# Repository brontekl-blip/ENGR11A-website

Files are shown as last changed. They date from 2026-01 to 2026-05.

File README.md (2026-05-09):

**Automatic Medicine Dispenser**

<p>
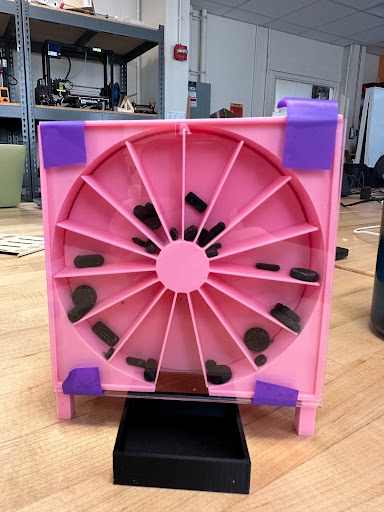
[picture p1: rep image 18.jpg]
  
</p> 
<p>
  Currently, older adults with dementia or general memory issues struggle to remember to take their medications and manage multiple medications. This means that these individuals may not take their medications at the correct times or at all and might need help from a caretaker. We want these individuals to be able to manage their medications independently and have confidence in themselves. Our project is a medicine dispenser that can be preloaded for a full week, including separate morning and night compartments, for a total of 14 functional compartments and 1 refill position. 
</p>

**Bill of Materials**
- 2 9V batteries  
- A small breadboard (you can use basically any breadboard as long as it accommodates the necessary design size) 
- A couple of different jumper wires (recommended package - [link](https://a.co/d/06EYdTq6)) 
- A USB Printer Cable
- An LED (depending on how much light you want, get as many LEDs).
- DC3V-12V DC Geared Motor (recommended package - [link](https://a.co/d/02fzENU2)) 
- 2 regular wires
- A cable to connect the battery 
- Resistor (higher than 222 ohms) 
- A 9V battery clip
- A DRV8833 Dual H-Bridge DC Motor Driver Module H
- 4 Hall Effect Magnetic Sensor Module 3144E  ([link](https://a.co/d/08p1yAlN))
- 32 Magnets, diameter of 5mm and depth of 2-3mm
- PLA Printer Filament Roll

**Required/Recommended Tools**
- Arduino-compatible coding program
- A soldering machine is not needed, but is suggested; it is commonly found in a library.
- A Rubber Mallet
- 3D Printer (originally designed for print on Prusa MINI)

**Mechanical Assembly**
<p>
  PS - The place in which you place your jumper wires to the breadboards, for example, for hall sensors, is based on how you coded into the Arduino. In this case, or if you are using the <a href="https://docs.google.com/document/d/1jkpZ4H0KWvsoafJ_Ff6-uf_Do_P35tXl_jxYF_B4JnI/edit?tab=t.nf3fixb14pqj">original code</a>, the hall sensors go to pin number 2, 3, 4, 5, the buzzer to pin number 6 and then lead to 13. For an easier time, try to color coordinate. For example, as you will see in my design, I try to use black or darker jumper wires for ground, a lighter color such as yellow for power, and then medium colors such as blue and purple for signals.
</p>
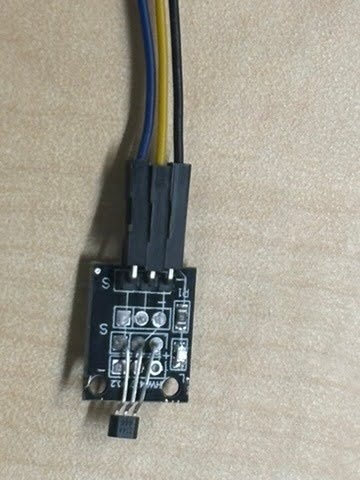
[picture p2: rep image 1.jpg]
1. For every hall sensor, using the male-to-female jumper wires, connect them to the hall sensor and buzzer, remembering which colors of wires go where (look in the picture for reference) 
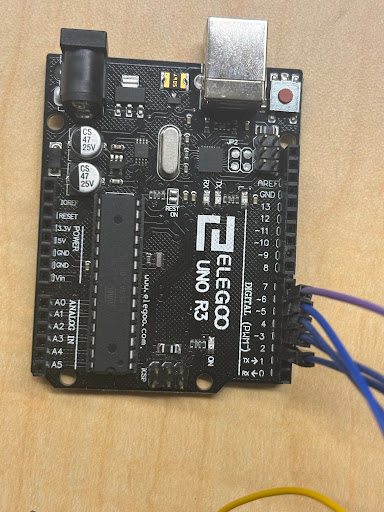
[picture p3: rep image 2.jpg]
2. Now connect the blue jumper wire (or whatever color you used) to the corresponding pin numbers (2, 3, 4, 5) and the purple jumper wire (buzzer) to pin number 6. 
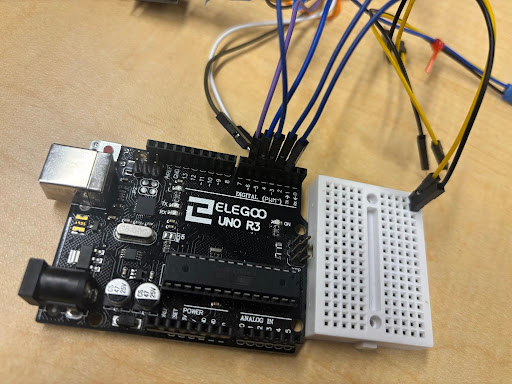
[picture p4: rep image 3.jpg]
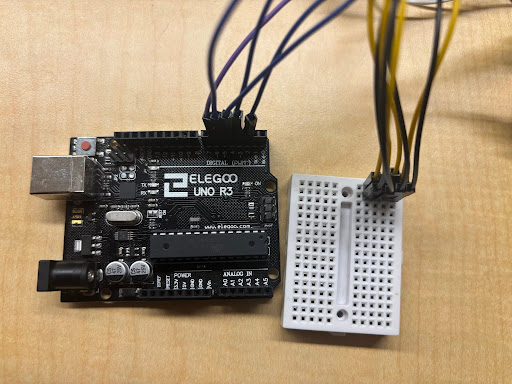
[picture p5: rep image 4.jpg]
3. Then, using the breadboard, align all the yellow jumper wire (power) on a single row then the black jumper wires on the row below it.  
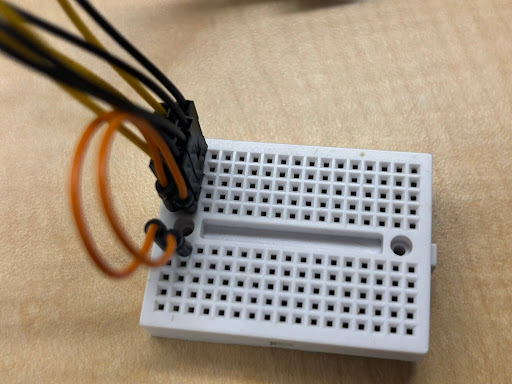
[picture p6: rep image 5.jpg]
4. If using the small breadboard, use two male to male wires to connect each row to the corresponding row next to it. 
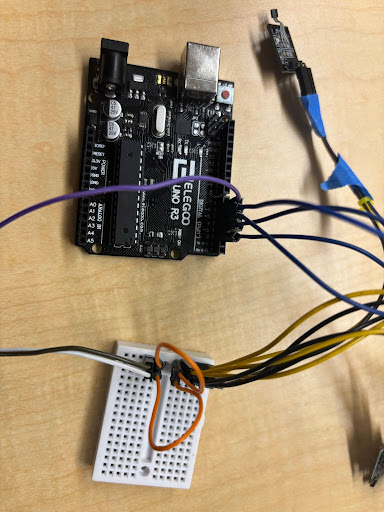
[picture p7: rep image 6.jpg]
5. Then connect the corresponding buzzer cable to power and ground. (In this case, power was connected through a white jumper cable and a brown cable for ground). 
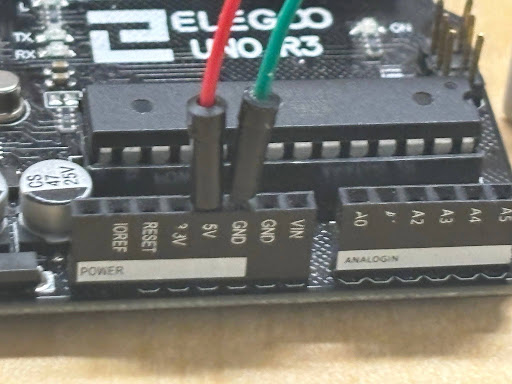
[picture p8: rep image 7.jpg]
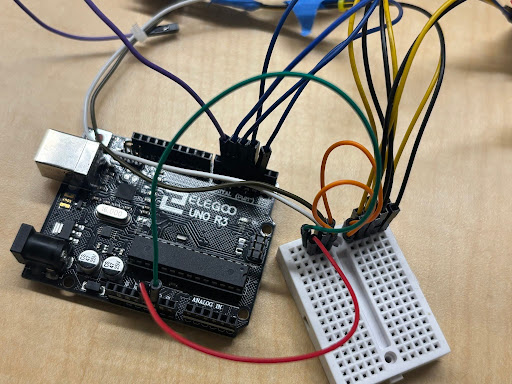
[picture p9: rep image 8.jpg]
6. Using male-to-male wires, connect one of the wires to 5V on the Arduino board and then to the power supply on the breadboard. Then connect one of the wires to GND on the Arduino board and then to the ground corresponding on the breadboard. (red is power and green is ground.)  
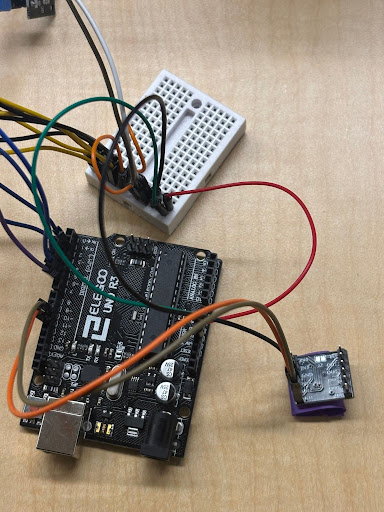
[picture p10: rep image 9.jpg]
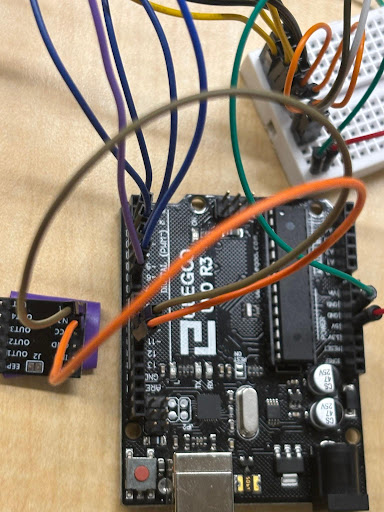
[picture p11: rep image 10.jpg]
7. Then move on to the Dual H-Bridge; connect IN1 and IN2 to the corresponding pin number on the arduino board, pin 10 and pin 11.  
8. Using another male-to-female connector, connect GND from the dual H-bridge to one of the spaces on the row of GND on the breadboard.
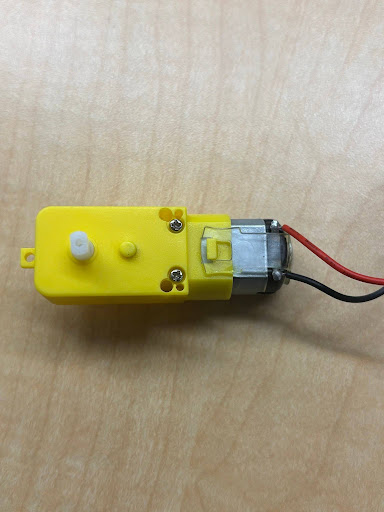
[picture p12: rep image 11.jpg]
9. Then using 2 wires, slowly strip some insulating part and tie and wrap the wires over the little flaps from the tip of the wire. Bonus points if you can solder them together for a stronger connection. 
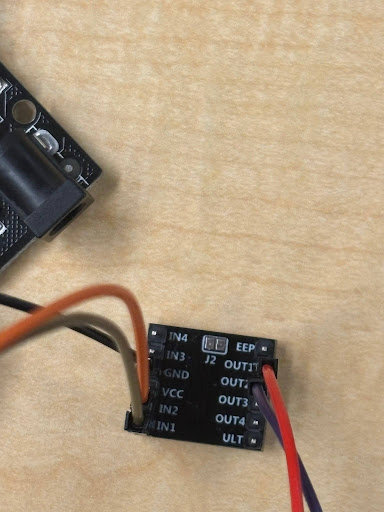
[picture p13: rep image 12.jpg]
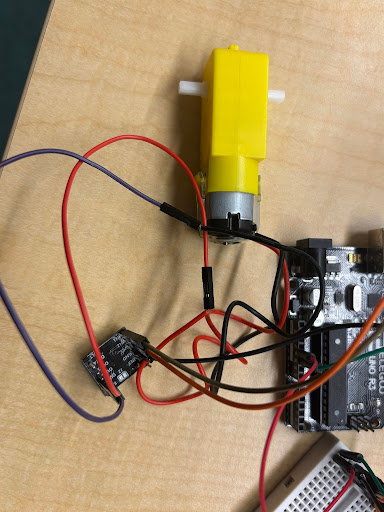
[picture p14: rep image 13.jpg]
10. Then use two female-to-female wires, to connect the wires to OUT1 and OUT2, connecting the whole motor to wires, (this doesn’t matter which one; it only determines which direction the motor spins)  
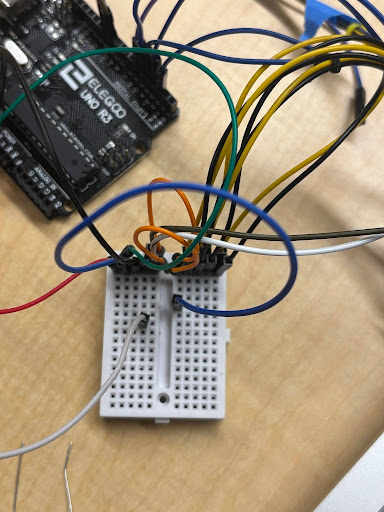
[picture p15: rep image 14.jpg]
11. Use an additional male-to-male wire, to connect to the designated ground breadboard and connect it to an additional row on the breadboard (look at the image for an example; it is the blue wire) 
12. Then connect the black wire of the 9V battery clip to the row connected to GND of the Arduino board.
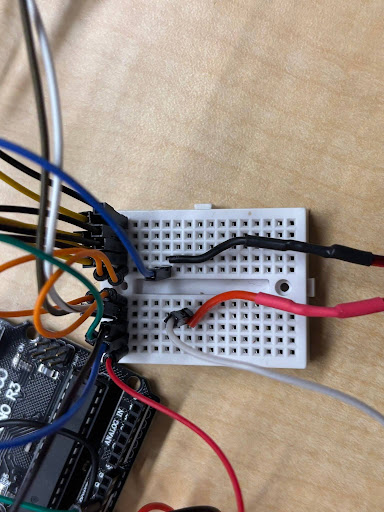
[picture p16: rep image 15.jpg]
13. Using a male-to-female connector, connect the pin labeled EEP on the breadboard, then connect the red wire for the battery to it. (For more context, the white wire connects to EEP on board 2.) 
14. To connect the LED, using a male-to-male connector, connect the LED pin number, in this case 13, to the breadboard on an empty row. (This is so you have multiple LED pins and do not have to program or use additional pin numbers).
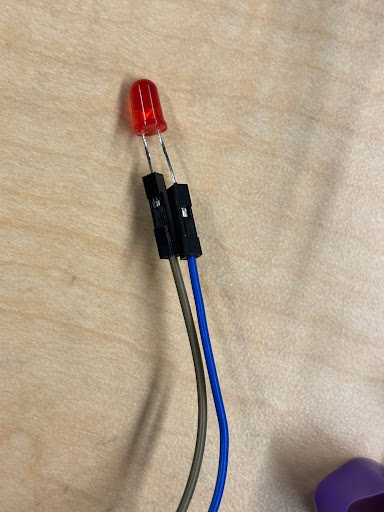
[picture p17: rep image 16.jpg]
15. Connect both LED pins to a male-to-female jumper wire (making sure to remember which one is which); this is to make sure that the LEDs have more flexibility. In this case, the blue wire is the longer leg of the LED, and the black wire is the shorter leg of the LED. 
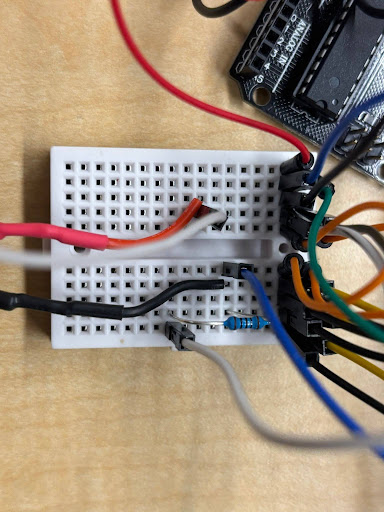
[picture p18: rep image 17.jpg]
16. Then take a resistor and put one of the pins of the resistor to the row that connects to the LED pin number and one to the designated ground rows on the breadboards. 
17. Then connect the LED to both the designated ground row and the LED row. Connect the wire with the shorter leg (cathode) to a GND row and the longer leg (anode) to the row that connects to the LED pin number.
18. To start, get the code file from above, then plug the USB printer cable into the Arduino board and back into your computer (based on the circuit board you are using, you might need a different cable to connect your circuit board to your computer).

**3D Print and Assembly**
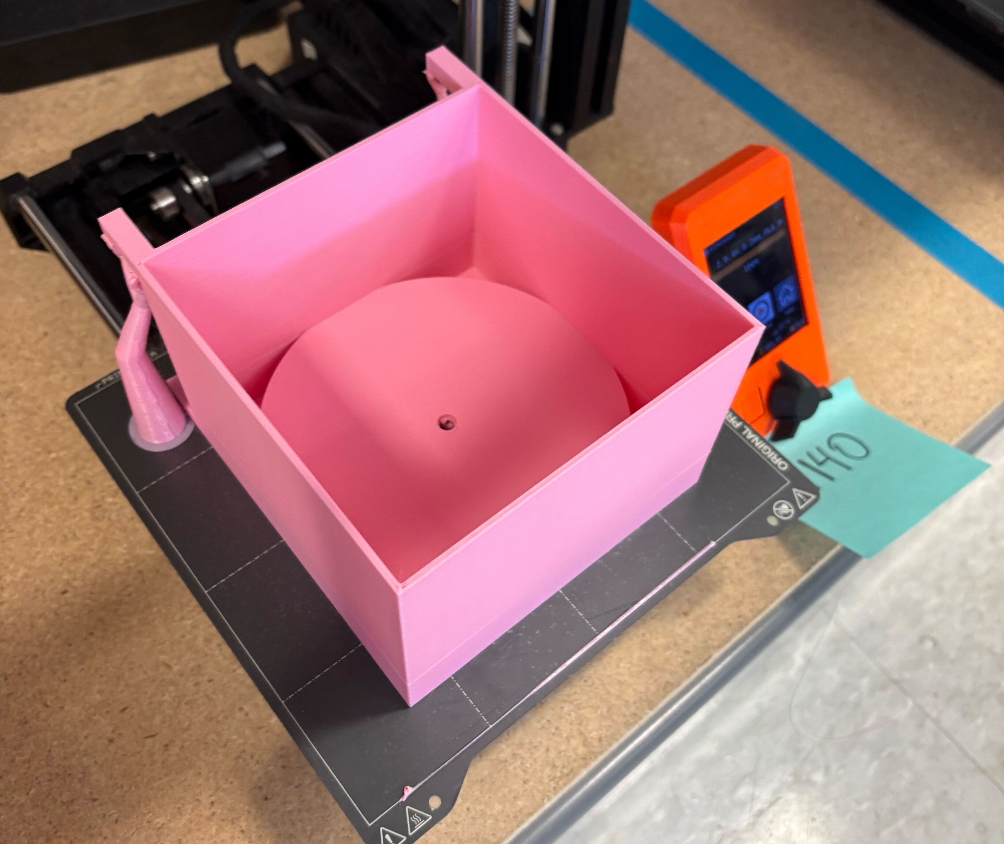
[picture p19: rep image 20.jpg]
1. Print Settings: Final Cycle Outer Box should be printed on its front face, with automatic paint-on supports. 
2. Print the <a href="./Final Cycle Outer Box.stl" download>Final Cycle Outer Box</a>
3. Print the <a href="./Final Cycle Wheel.stl" download>Final Cycle Outer Box</a>
4. Print the <a href="./Final Cycle Medicine Tray.stl" download>Final Cycle Outer Box</a>
5. Put magnets in the designated holes, using a mallet to fully insert. Ensure that each magnet is facing the correct way before fully inserting, preferably using the hall effect sensor to confirm it is activated. If a magnet is placed backwards, carefully use a heatgun to soften the surrounding plastic, then use a stronger magnet to pull it out of the hole. After this, you will most likely need to super glue the magnet back into place, since the hole will no longer be a snug fit. If the magnets are too small, you can super glue them into place. 
6. Trim down the motor shaft so the wheel does not excessively protrude out the front of the outer box.
7. Insert the motor shaft through the back of the outer box and into the back of the wheel. You may choose to glue the shaft into its socket on the back of the wheel, but only do this if you are certain the wheel is not excessively protruding out the front.
8. Secure the motor in place on the back of the outer box, ensuring the shaft is perpendicular to the back of the outer box. You may use tape, glue, or modify the outer box print to include a mount.

**Suggested Path to Functionality**
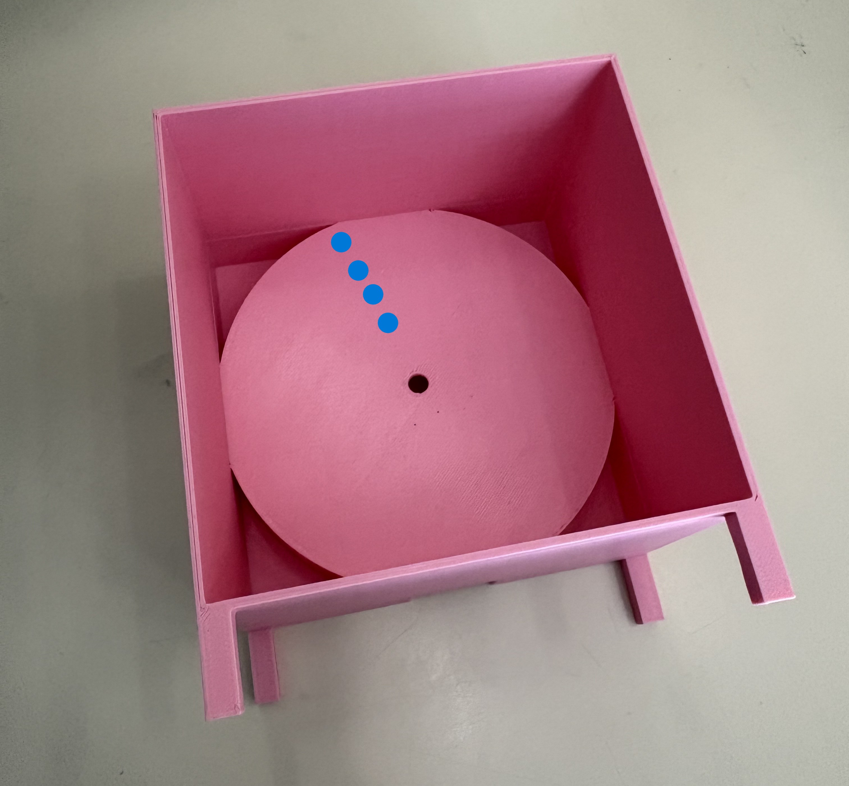
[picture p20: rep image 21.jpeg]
1. Attach the hall effect sensors to the back of the outer box in the positions where each magnet slot would align. Ensure the correct hall effect sensor placement based on the code and pins. Below is the approximate suggested location for positioning. 
2. Add a door, latch, and hinge to the front of the box so that it can be opened for refill and closed to prevent medicine from falling out when upright and functional.
3. Add a door, latch, and hinge to the back of the box so that it can be opened for maintenance and closed during usage.
4. Modify code to release medication at the desired times of day.

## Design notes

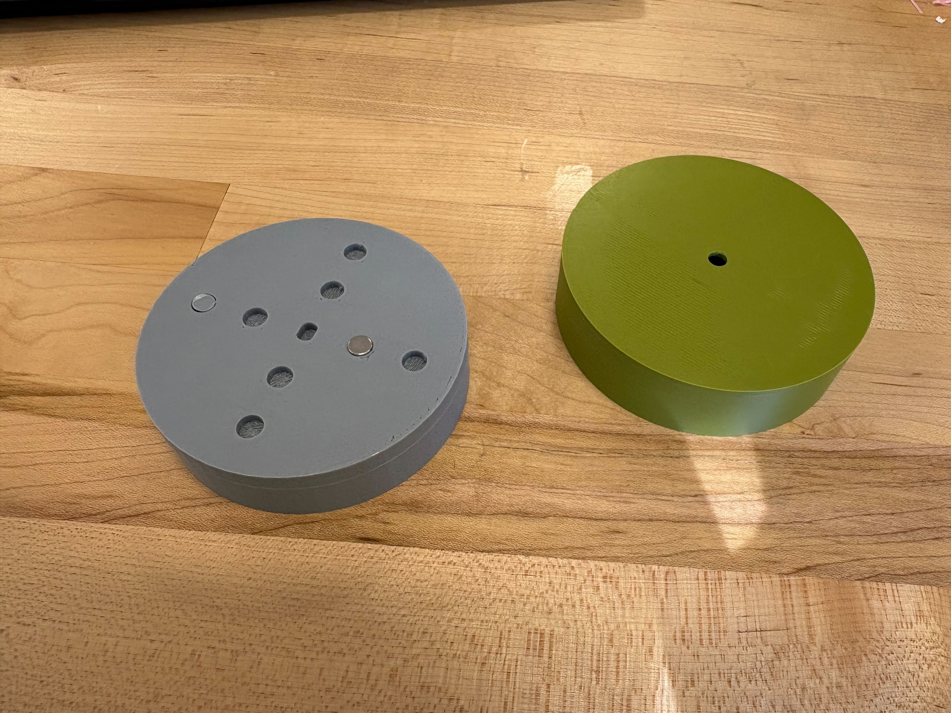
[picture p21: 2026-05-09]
assets/img/portfolio/project5/cycle 2 product 8.jpg

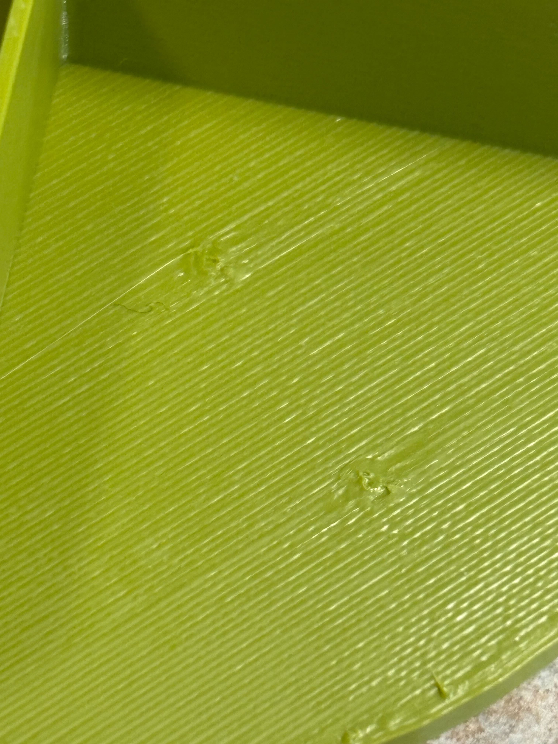
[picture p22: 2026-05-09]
assets/img/portfolio/project5/cycle 2 product 3.jpg

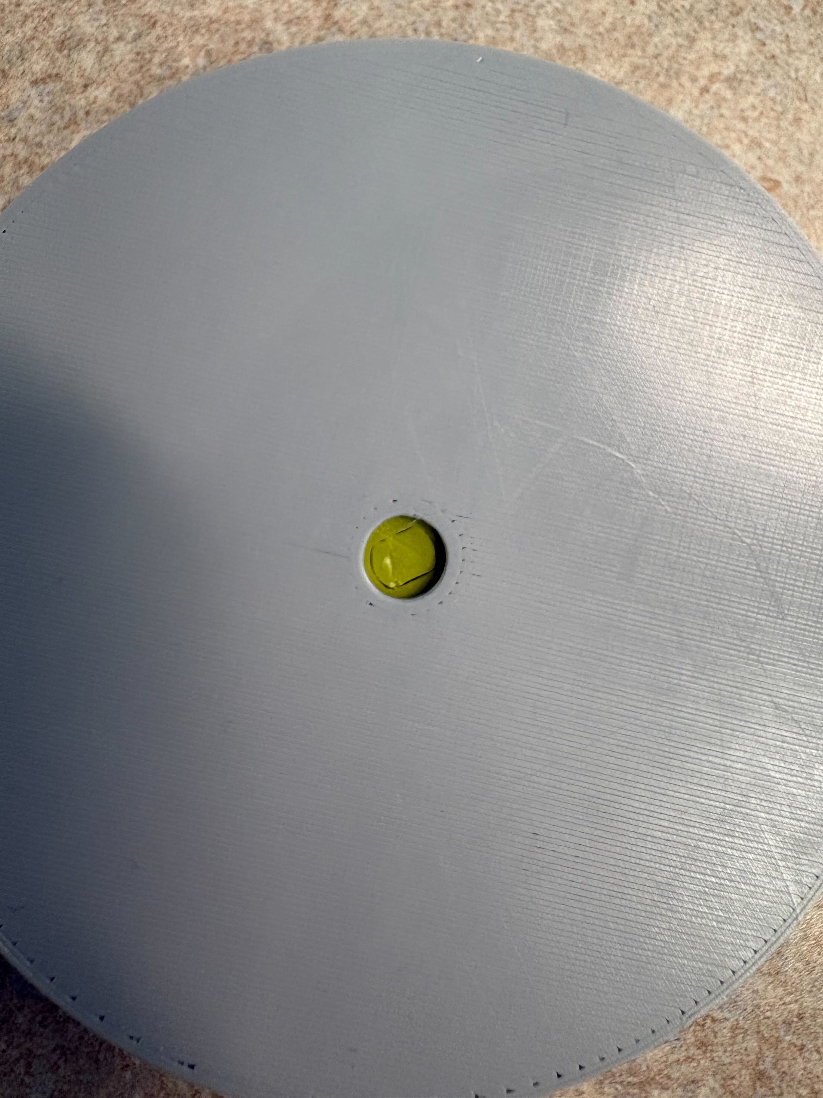
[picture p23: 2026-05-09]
assets/img/portfolio/project5/cycle 2 product 1.jpg

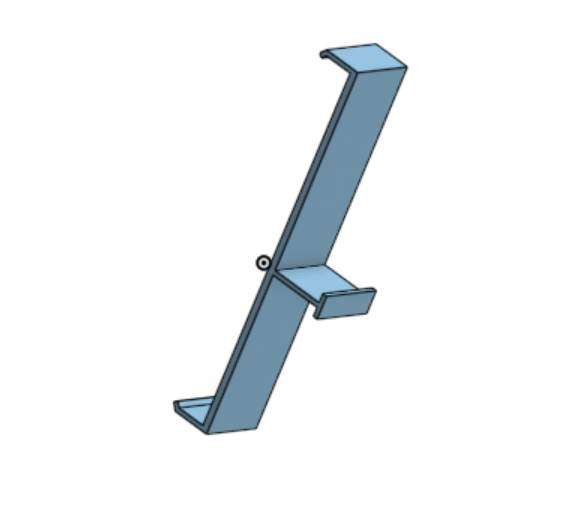
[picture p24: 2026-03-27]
assets/img/portfolio/project4/accessory design 8.png

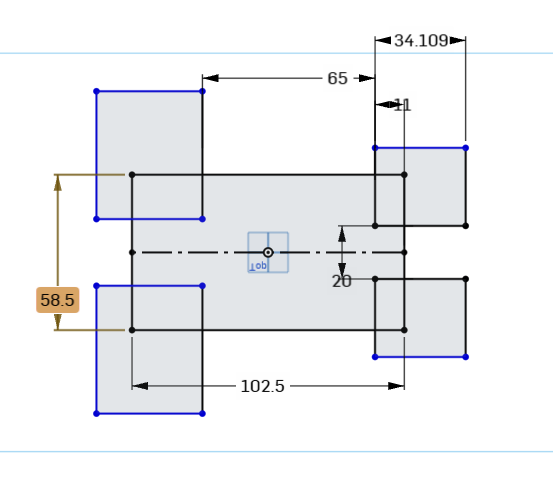
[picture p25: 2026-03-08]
assets/img/portfolio/project3/carbox laser cut joyce v2 dimensions.png

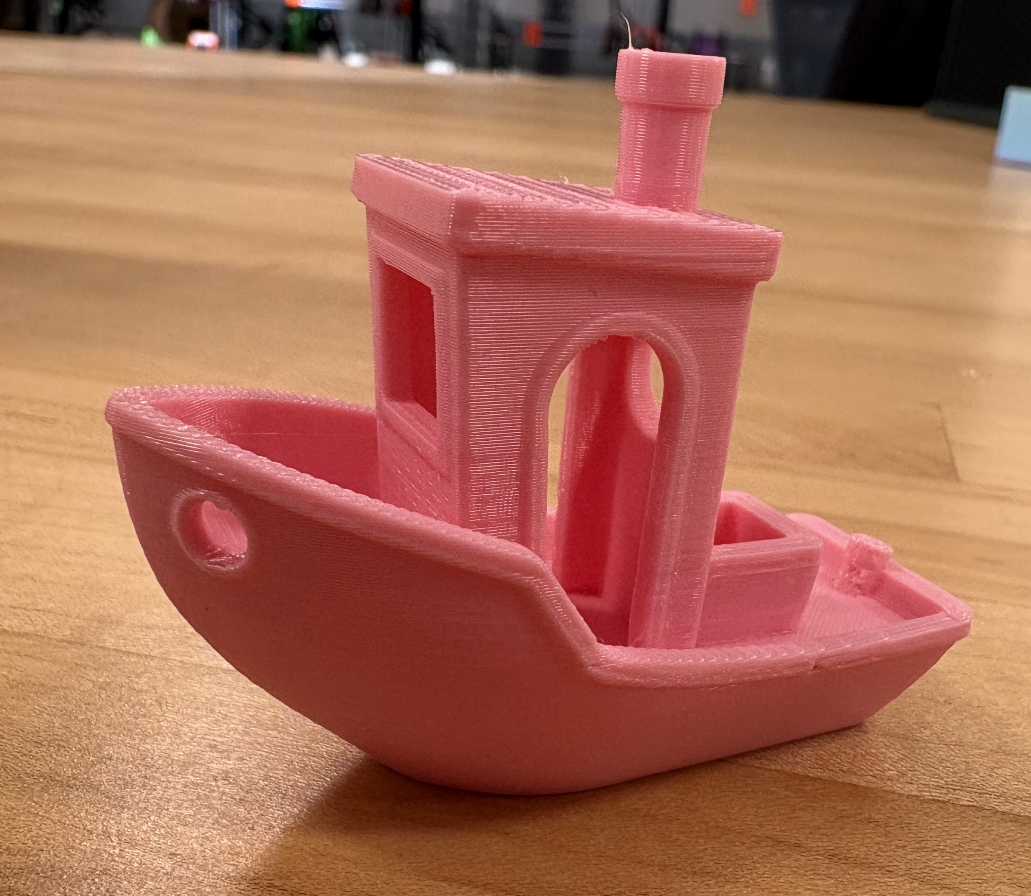
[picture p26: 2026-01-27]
assets/img/portfolio/project1/Benchy2.jpeg

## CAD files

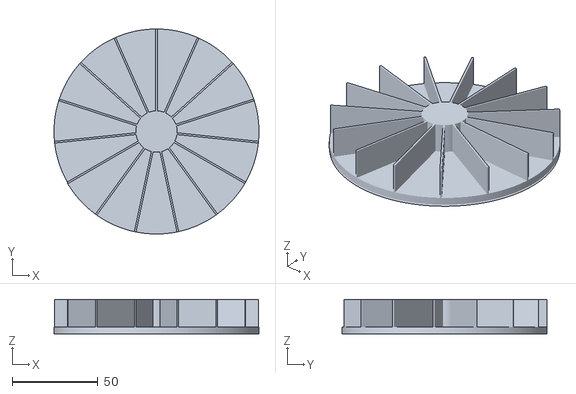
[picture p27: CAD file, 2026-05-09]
Final Cycle Wheel.stl
119.4 x 119.4 x 21.0

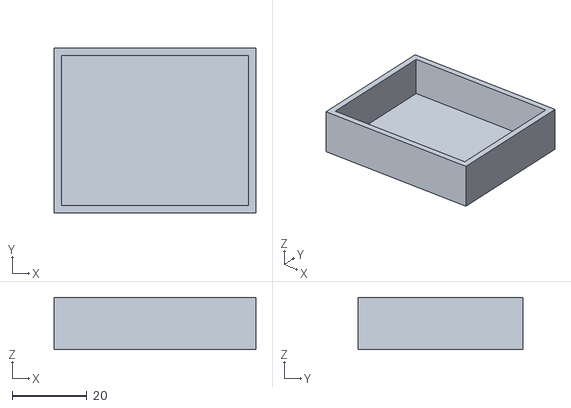
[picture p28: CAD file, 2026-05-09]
Final Cycle Medicine Tray.stl
54.0 x 44.0 x 14.0

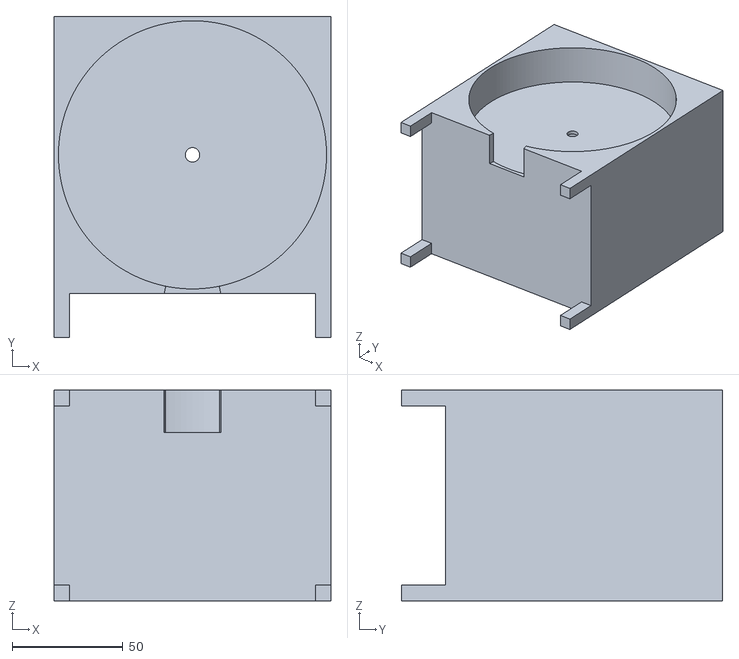
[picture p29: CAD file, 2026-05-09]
Final Cycle Outer Box.stl
125.0 x 145.0 x 95.0

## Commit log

2026-04-02 Design Project 5: Stage 1 Submission
2026-05-09 stl files
    [Final Cycle Medicine Tray.stl, Final Cycle Outer Box.stl, Final Cycle Wheel.stl]
